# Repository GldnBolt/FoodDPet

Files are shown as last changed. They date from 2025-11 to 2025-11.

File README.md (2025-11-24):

# FoodDPet - Alimentador Automático para Mascotas
## Proposito del Proyecto
FoodDPet es un sistema automatizado diseñado para facilitar la alimentación de mascotas de manera inteligente y controlada. Este proyecto integra hardware embebido y una aplicación web para proporcionar una solución completa que permite a los dueños de mascotas programar y monitorear la alimentación de sus animales de compañía de forma remota.

### DEPENDENCIAS NECESARIAS

### Aplicación Web
- Node.js con npm
- Angular

Instalar Node.js y ejecutar el siguiente comando para instalar las dependencias

``` bash
 npm install 
 npm install -g @angular/cli
```
### Software del microcontrolador

Instalar el IDE de Arduino, e instalar la siguiente librerias: 
- Adafruit VL53L1X por Adafruit

Además de añadir el soporte para tarjetas:
- esp32 por Espressif Systems

### PASOS DE EJECUCIÓN

### Aplicación Web

Dentro de la carpeta WebApp, ejecutar el siguiente comando para abrir la aplicación en modo desarrollo

```bash 
ng serve -o
```

### Software del microcontrolador

Seleccionar desde las tarjetas disponibles en el IDE de Arduino: ESP32S3 Dev Module.

Reemplazar las variables ssid y password por las credenciales de la red a la que se va a conectar el alimentador.

Compilar y subir el código desde el IDE.

Introducir en la aplicación la IP que se imprime después de iniciar el sistema.

### LISTA DE MATERIALES CON COSTOS 
- ESP32: $15,95
- Sensor ultrasónico HC-SR05: $4.49 
- Sensor laser Tof400c: $9.95 
- Stepper Driver A4988: $5.99
- Motor Stepper: $8.30
- Placa Perforada: $3.75
- Cautín y estaño: $24.95
- Transistor NMOS: $0.25
- Pulsador de 4 pines: $0.20
- 2 Resistencias de 220 ohmios: $0.10
- Jumpers: $2.20
- Modelo 3d(Cascasa exterior): $20.00

### DIAGRAMAS DEL CIRCUITO

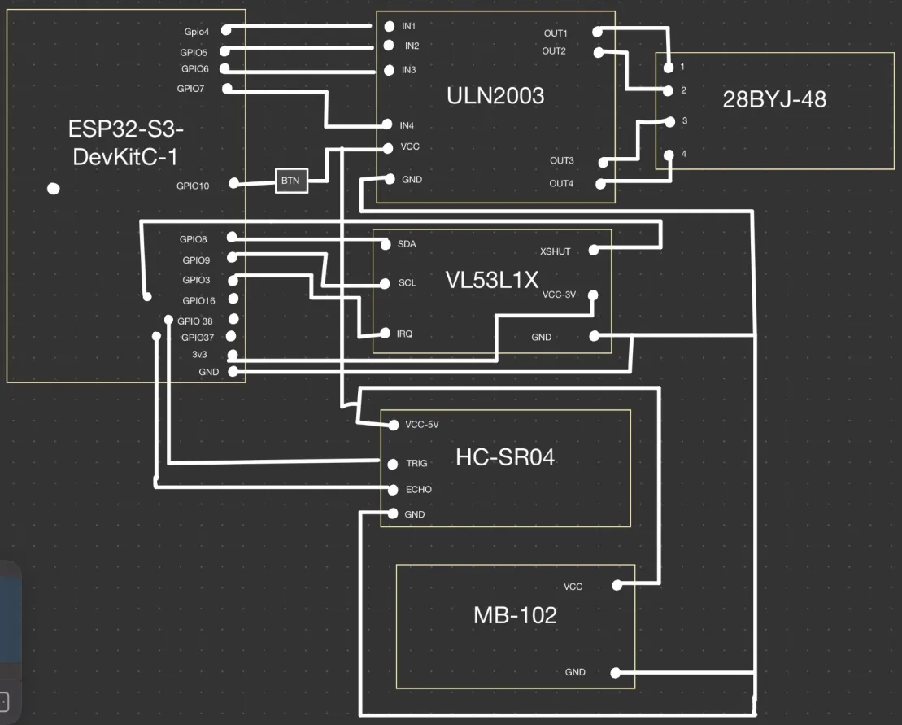
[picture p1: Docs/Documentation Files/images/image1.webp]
Diagrama del circuito


### DEMOSTRACIONES DE USO
En el siguiente enlace se puede observar una demostración del funcionamiento del alimentador automático FoodDPet:
[Demostración FoodDPet](https://www.youtube.com/@fabiola8169)

### Información Adicional
Para más detalle sobre el diseño del proyecto, incluyendo el diseño de hardware, arquitectura de software, aplicación de usuario y comunicación, por favor consulte la documentación completa en el archivo Documentacion.md. Esta documentación incluye descripciones detalladas de los componentes utilizados y demás explicaciones técnicas, así como los diagramas de flujo del software y conexiones de hardware.

Se recomienda además utilizar herramientas de simulación y diseño como Tinkercad para validar los diagramas y conexiones antes de la implementación física del proyecto. Para este proyecto, puede encontrar los mismos en la documentación adjunta. 

Para los diseños 3d de la carcasa se sugiere el uso del software de fusion360 o cualquier otro software de modelado 3d de su preferencia. En la documentación se incluyen los archivos necesarios para la impresión 3d de la carcasa del robot. Se recomienda ajustar las dimensiones según las necesidades específicas del usuario.

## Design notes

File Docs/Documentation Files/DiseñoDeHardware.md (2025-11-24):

# Diseño de Hardware
FoodDPet está construido alrededor de un microcontrolador ESP32, elegido por su capacidad de procesamiento, conectividad Wi-Fi integrada y bajo consumo energético. El ESP32 permite una comunicación eficiente con la aplicación web y maneja múltiples sensores y actuadores necesarios para el funcionamiento del robot. Su elegibilidad se basa en su capacidad de soporte de programas complejos, versatilidad y soporte para diversas interfaces de comunicación.

## Sensores y Actuadores

El robot utiliza una variedad de sensores para monitorear su entorno y asegurar un funcionamiento óptimo. Entre ellos se incluyen:

- Sensor ultrasónico HC-SR05: Utilizado para medir la cercanía del alimento a la tapa del robot para monitorear el nivel de comida.

- Sensor Tof400c : Empleado para la detección precisa de presencia del animal cerca del dispensador para activar el pedido de alimento.

- Motor Stepper: Utilizado para mover el tornillo de dispensado de alimento.

## Analisis de Consumo Energético

El consumo energético del robot ha sido cuidadosamente analizado para garantizar una operación eficiente y prolongada. El ESP32 tiene un consumo promedio de 80 mA en modo activo, mientras que los sensores ultrasónicos y el servomotor tienen consumos adicionales que varían según su uso. Se ha implementado un sistema de gestión de energía por medio de reguladores de voltaje y jacks de alimentacion para tener un consumo optimizado y velar por la duración de los componentes.

## Diagramas de Conexión
A continuación se presentan los diagramas de conexión que ilustran cómo se interconectan los diferentes componentes del robot, se utiliza la herramienta de Tinkercad para el diseño de circuitos y simulaciones. Cabe destacar que el diseño final del hardware no es complemente reflejado en Tinkercad, por temas de limitaciones de la herramienta no todos los componentes están disponibles,
pero se utilizó para validar las conexiones y el funcionamiento básico de los componentes:

Diagrama de conexiones basico

## Consideraciones de Diseño Mecánico

El mecanismo principal del robot consiste en un tornillo infinito, este es el mecanismo principal que permite el movimiento del dispensador de comida. El tornillo infinito es accionado por un motor paso a paso, que proporciona la precisión necesaria para dispensar cantidades exactas de alimento. Este tornillo está hecho de un material resistente y duradero para soportar el uso continuo y las condiciones ambientales a las que estará expuesto el robot. Se opto por este mecanismo debido a su capacidad para proporcionar un movimiento suave y controlado, lo que es esencial para el correcto funcionamiento del dispensador de comida. Por otro lado, el diseño mecánico también incluye un sistema de montaje para los sensores y actuadores, asegurando que estén posicionados de manera óptima para su funcionamiento. Este sistema de montaje es ajustable, permitiendo adaptarse a diferentes tamaños y tipos de alimentos. Se utilizaron materiales ligeros mediante impresion 3d lo que permite crear estructuras sólidas, resistentes, ligeras economicas y modulares lo que permite realizar ajustes y modificaciones de manera sencilla.

## Diseño de Tarjeta Perforada

El diseño de la tarjeta perforada se ha realizado teniendo en cuenta la disposición óptima de los componentes para minimizar interferencias y facilitar el ensamblaje. Se han utilizado software de diseño de PCB para crear un diseño compacto y eficiente, asegurando que todas las conexiones sean robustas y confiables. Este diseño representa la versión final del hardware del robot FoodDPet, optimizado para su funcionalidad y durabilidad:

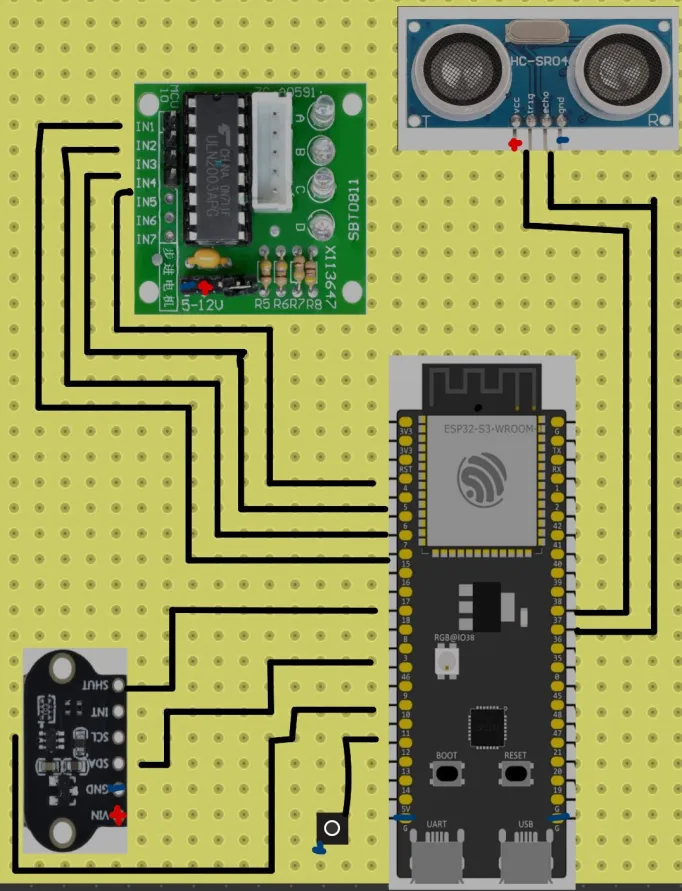
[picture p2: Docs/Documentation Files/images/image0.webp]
Diagrama de la tarjeta perforada
.

## Diseño de la Carcasa

La carcasa del robot ha sido diseñada para proteger los componentes internos y proporcionar una apariencia atractiva y funcional. Se ha utilizado software de modelado 3D para crear un diseño que sea fácil de ensamblar y mantener. La carcasa está hecha de materiales resistentes y ligeros como lo es el PLA. El diseño de la carcasa también incluye aberturas estratégicas para la ventilación y el acceso a los componentes internos, facilitando el mantenimiento y las actualizaciones futuras.

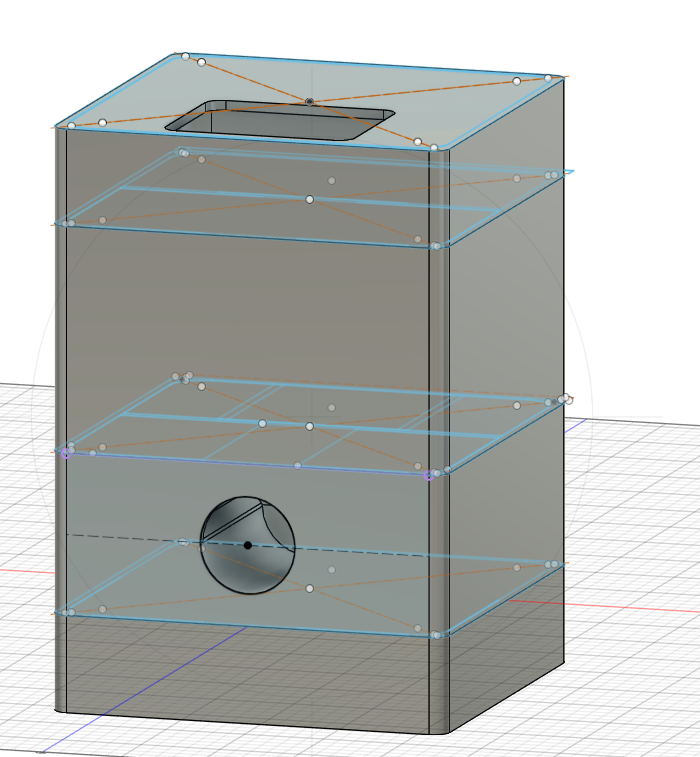
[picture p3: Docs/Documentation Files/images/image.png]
Modelo3D


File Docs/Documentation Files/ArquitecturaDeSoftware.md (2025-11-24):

## Arquitectura de Software

El programa principal que es el que controla el microcontrolador está escrito en Arduino/C++. El programa se conecta a la red WiFi para comunicarse con la aplicación web, mide constantemente los sensores para monitorear el nivel de comida y la presencia de la mascota, ejecuta los horarios programados para dispensar comida automáticamente, y guarda todos los datos importantes en memoria permanente para asegurar que no se pierdan.
El mismo está organizado para ser eficiente y responsivo, al cargar el programa este establece la conexion con los sensores, se conecta a la red WiFi, sincroniza la hora con internet, carga los datos almacenados, y luego entra en un bucle infinito donde atiende las solicitudes de la aplicación web. Este flujo se puede observar mejor de la siguiente manera:

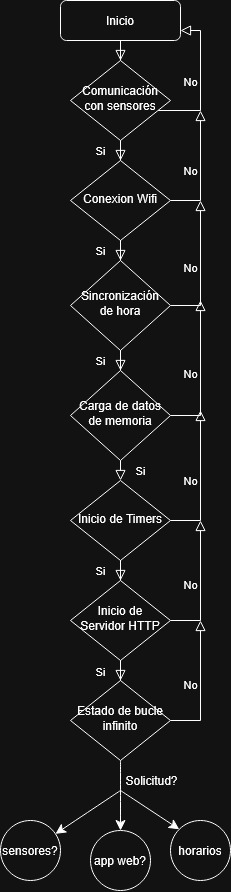
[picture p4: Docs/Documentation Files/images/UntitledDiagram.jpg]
Diagrama de conexiones basico


## Estrategias de Comunicación y Gestión de E/S 

Para los dispositivos de entrada y salida del esp 32 se han implementado diversas estrategias para asegurar una comunicación eficiente y confiable con los sensores y actuadores conectados. La decision fundamental fue combinar la comunicación tanto por interrupciones como por sondeo dependiendo del caso de uso. Lo anterior ya que no era factible ya que si se realizara solamente por sondeo el sistema no sabria exactamente cuando realizar la interrupcion sino que verificaria constantemente el estado de los sensores si hay proximidad lo que generaria un consumo innecesario de recursos y energia. Por otro lado, si se utilizara solamente por interrupciones, los sensor generarían una interrupción cada vez que detecte proximidad, interrumpiendo inmediatamente todo lo que el microcontrolador está haciendo. Por lo que se opto por una solución híbrida que combina ambos métodos para aprovechar las ventajas de cada uno. Más adelante se detallan cada una de las estrategias implementadas.

La primera es la utilizacion de contadores de tiempo que permiten ejecutar tareas periódicas sin bloquear el flujo principal del programa.  
Estos timers funcionan en paralelo con el resto del código, lo que significa que el microcontrolador pueda estar respondiendo a la aplicación web mientras simultáneamente está verificando horarios y escaneando sensores lo anterior permite que el sistema sea responsivo y esté sinconizado. 
Para los timers se definen dos, el timer de cada segundo y el del minuto, el inicial es para verificar en tiempo real los horarios programados y el segundo timer es para escanear el sensor ultrasónico cada minuto y detectar si la mascota está pidiendo comida.

Por otro lado, cada dispositivo tiene su propio protocolo de comunicación específico:

1. Sensor Ultrasonico: Este sensor utiliza un protocolo basado en pulsos. El microcontrolador envía un pulso de activación al sensor, que luego emite un pulso ultrasónico para por realizar las medias.

2. Sensor Láser: Este sensor utiliza el protocolo I2C para comunicarse con el microcontrolador por medio de dos cables SDA y SCL que permiten enviar y recibir datos de manera eficiente.

3. Motor: el microcontrolador activa una salida digital que enciende el motor durante el tiempo necesario.

4. Red WiFi: La comunicación con la aplicación web ocurre constantemente. El ESP32 actúa como un servidor HTTP pequeño que recibe solicitudes GET, POST, PUT y DELETE desde la aplicación, las procesa, y responde con datos en formato JSON.

## Organización de Memoria
Para el almacenamiento de datos se utiliza la memoria EEPROM del microcontrolador. Donde se guardan los horarios de alimentación programados por  medio de un json y las peticiones de alimentacion realizadas por medio de archivo de texto log. Para el manejo de estos archivos se utiliza la libreria de littlefs que permite crear un sistema de archivos en la memoria flash del microcontrolador. Se eligió esta manera de almacenamiento debido a su capacidad para manejar múltiples archivos y su facilidad de uso con el microcontrolador. 

La organización de la memoria se realiza de la siguiente manera:      
- Los primeros bytes de la memoria EEPROM se reservan para almacenar la cantidad de horarios programados. Esto permite al sistema saber cuántos horarios debe cargar al iniciar.

- A continuación, se asigna un bloque de memoria para cada horario programado. Cada bloque contiene la hora y minuto lo que facilita la lectura y escritura de horarios específicos sin afectar otros datos.

- Finalmente, se reserva un espacio adicional para almacenar el historial de alimentaciones realizadas. Cada entrada en el historial incluye la fecha y hora de la alimentación, así como el estado de la operación. Esto permite al usuario revisar el historial completo desde la aplicación web.

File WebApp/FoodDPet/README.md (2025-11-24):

# FoodDPet

This project was generated using [Angular CLI](https://github.com/angular/angular-cli) version 20.3.7.

## Development server

To start a local development server, run:

```bash
ng serve
```

Once the server is running, open your browser and navigate to `http://localhost:4200/`. The application will automatically reload whenever you modify any of the source files.

## Code scaffolding

Angular CLI includes powerful code scaffolding tools. To generate a new component, run:

```bash
ng generate component component-name
```

For a complete list of available schematics (such as `components`, `directives`, or `pipes`), run:

```bash
ng generate --help
```

## Building

To build the project run:

```bash
ng build
```

This will compile your project and store the build artifacts in the `dist/` directory. By default, the production build optimizes your application for performance and speed.

## Running unit tests

To execute unit tests with the [Karma](https://karma-runner.github.io) test runner, use the following command:

```bash
ng test
```

## Running end-to-end tests

For end-to-end (e2e) testing, run:

```bash
ng e2e
```

Angular CLI does not come with an end-to-end testing framework by default. You can choose one that suits your needs.

## Additional Resources

For more information on using the Angular CLI, including detailed command references, visit the [Angular CLI Overview and Command Reference](https://angular.dev/tools/cli) page.

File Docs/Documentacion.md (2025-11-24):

# Documentación de Diseño del Proyecto
---

## **Información del Proyecto**

- **Nombre del Proyecto**: FoodDPet - Alimentador Automatico para Mascotas

- **Equipo**: Equipo FoodDPet

- **Integrantes**:
  - Integrante 1: Andres Blanco Coto
  - Integrante 2: Karina Martínez Guerrero 
  - Integrante 3: Fabiola Meléndez Sequeira
  - Integrante 4: Jeremy Noryan Serracin Oporta
- **Profesor**: Jeferson Gonzalez Gomez
- **Materia**: Arquitectura de Computadores

# Índice

1. [Diseño de Hardware](./Documentation%20files/DiseñoDeHardware.md)
2. [Arquitectura de software](./Documentation%20files/ArquitecturaDeSoftware.md)
3. [Aplicación de usuario y comunicación](./Documentation%20files/AplicacionYComunicacion.md)

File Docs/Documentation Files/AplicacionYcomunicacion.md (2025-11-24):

# Aplicación web desarrollada

La aplicación web de FoodDPet está diseñada para gestionar el sistema automático de alimentación de mascotas. Permite a los dueños de mascotas programar horarios de comida, monitorear el estado del comedero y mantener un registro histórico de las alimentaciones. La aplicación ha sido construida con tecnologías web modernas y responsivas, pensando en una experiencia de usuario intuitiva que cualquiera pueda usar sin necesidad de conocimientos técnicos.

## Arquitectura de la Aplicación

La aplicación está construida con Angular, un framework moderno y robusto para crear aplicaciones web interactivas. Se complementa con PrimeNG, una librería de componentes visuales profesionales y listos para usar, lo que facilita la creación de interfaces atractivas y funcionales. Para la lógica reactiva y manejo de datos en tiempo real, utiliza RxJS. El código está escrito en TypeScript, un lenguaje que extiende JavaScript con características de programación orientada a objetos, haciendo el código más seguro, mantenible y escalable. Las pruebas se realizan con Jasmine y Karma, herramientas estándar en el ecosistema Angular.

## Interfaces de Usuario

La aplicación presenta dos vistas principales, cada una diseñada para cumplir un propósito específico en la gestión de la alimentación de tu mascota. Además de facilitar el control y monitoreo del comedero por medio de tablas, indicadores e historiales explicados más adelante.

1. **Panel de Control (Dashboard)**

Es la primera vista que ves al abrir la aplicación. Aquí se puede ver el estado actual del comedero automático. Incluye: 
- Indicador visual del nivel de comida representado como un porcentaje de 0 a 100% que tan lleno está el comedero.
- Un estado que clasifica si el comedero está "Bajo", "Medio" o "Alto" de comida.
- Una tabla de solicitudes que muestra un histórico de las últimas veces que se le dio comida a la mascota, incluyendo la hora exacta y si la operación se completó correctamente.

La aplicación permite tambien completar o cancelar manualmente una solicitud de alimentación.

2. **Horario de Alimentación (Food Schedule)**

En esta seccion se define cuándo y cuánta comida quieres que reciba tu mascota. Funciona como un calendario de alimentación. La misma permite:
- Agregar nuevos horarios de alimentación, especificando la hora en la que se desea alimentar a la mascota.
- Ver todos los horarios de alimentación programados.
- Editar horarios de alimentación existentes.
- Activar o desactivar horarios de alimentación.
- Eliminar horarios de alimentación cuando ya no sean necesarios.

---
## Protocolos de Comunicación Robot-Aplicación

La aplicación web se comunica con el dispensador automático a través del microcontrolador que es el que conecta todo del sistema. Este chip está conectado por WiFi y constantemente está pendiente de recibir órdenes desde la aplicación.

Al presionar un boton desde la aplicación web la aplicación recopila la información correspondiente y envia un mensaje al microcontrolador el cual procesa la información y ejecuta la acción solicitada. Este microcontrolador también envía datos de vuelta a la aplicación, como el nivel actual de comida y el estado de las solicitudes comunicandose a su misma vez con cada uno de los sensores. 

El microcontrolador tiene un reloj interno sincronizado con los servidores de hora de internet, así que siempre sabe la hora exacta. El mismo cada segundo verifica si la hora actual coincide con alguno de los horarios programados. Cuando coincide se verifica que el horario esté activo y de ser así le ordena al motor que dispense la comida y registra en el historial de que se realizó la alimentación.

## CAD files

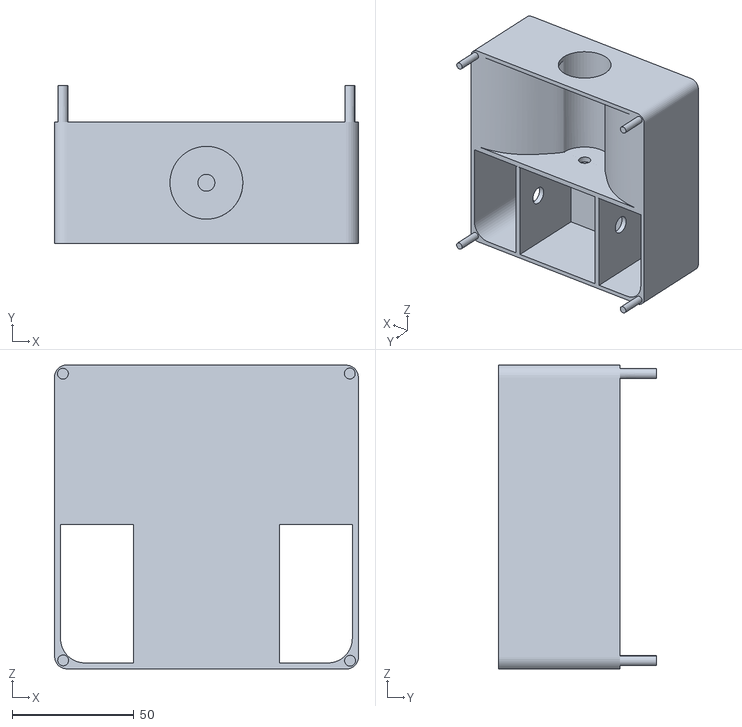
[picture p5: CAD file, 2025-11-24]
Docs/3dDesign/Segundo nivel.stl
125.1 x 65.0 x 125.1

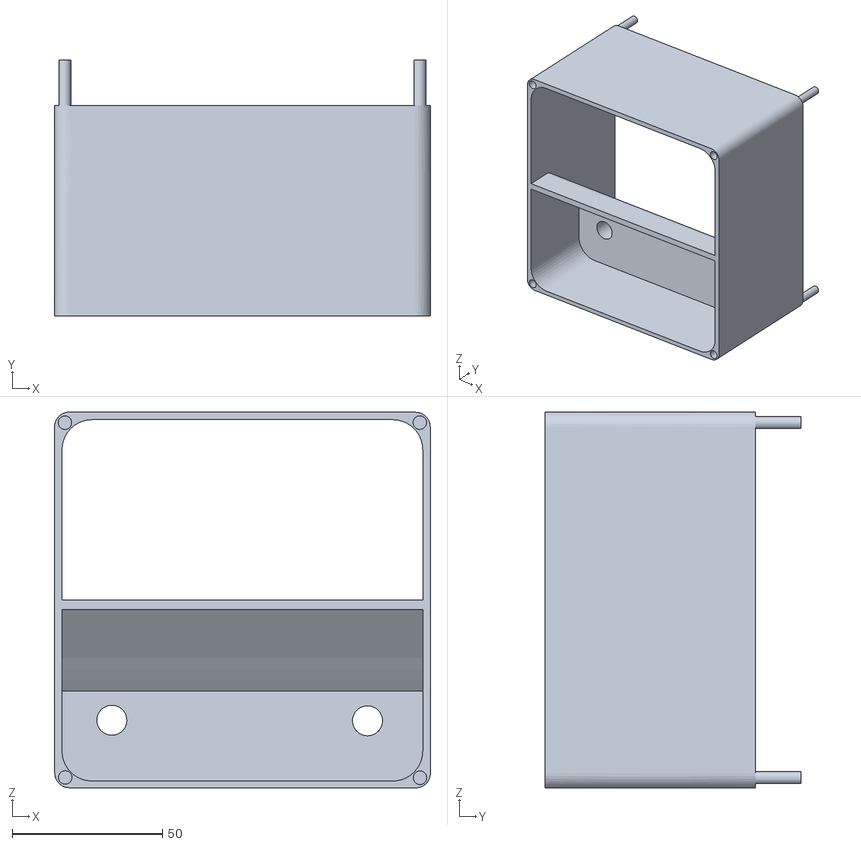
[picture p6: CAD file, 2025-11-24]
Docs/3dDesign/Tercer Nivel.stl
125.1 x 85.0 x 125.1

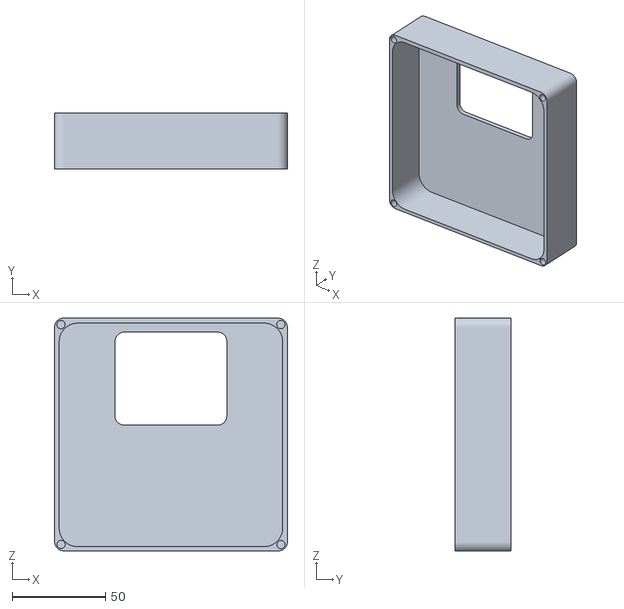
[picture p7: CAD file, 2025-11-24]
Docs/3dDesign/tapa.stl
125.1 x 30.0 x 125.1

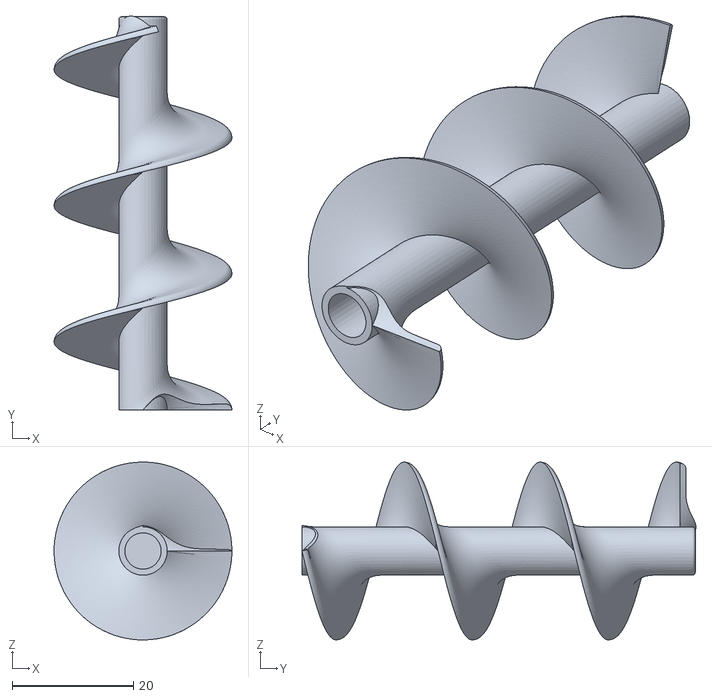
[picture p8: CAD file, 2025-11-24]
Docs/3dDesign/screw.stl
29.4 x 65.1 x 29.4

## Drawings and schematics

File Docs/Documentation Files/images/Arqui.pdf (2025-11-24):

A

1 | 2 | 3 | 4 | 5 | 6

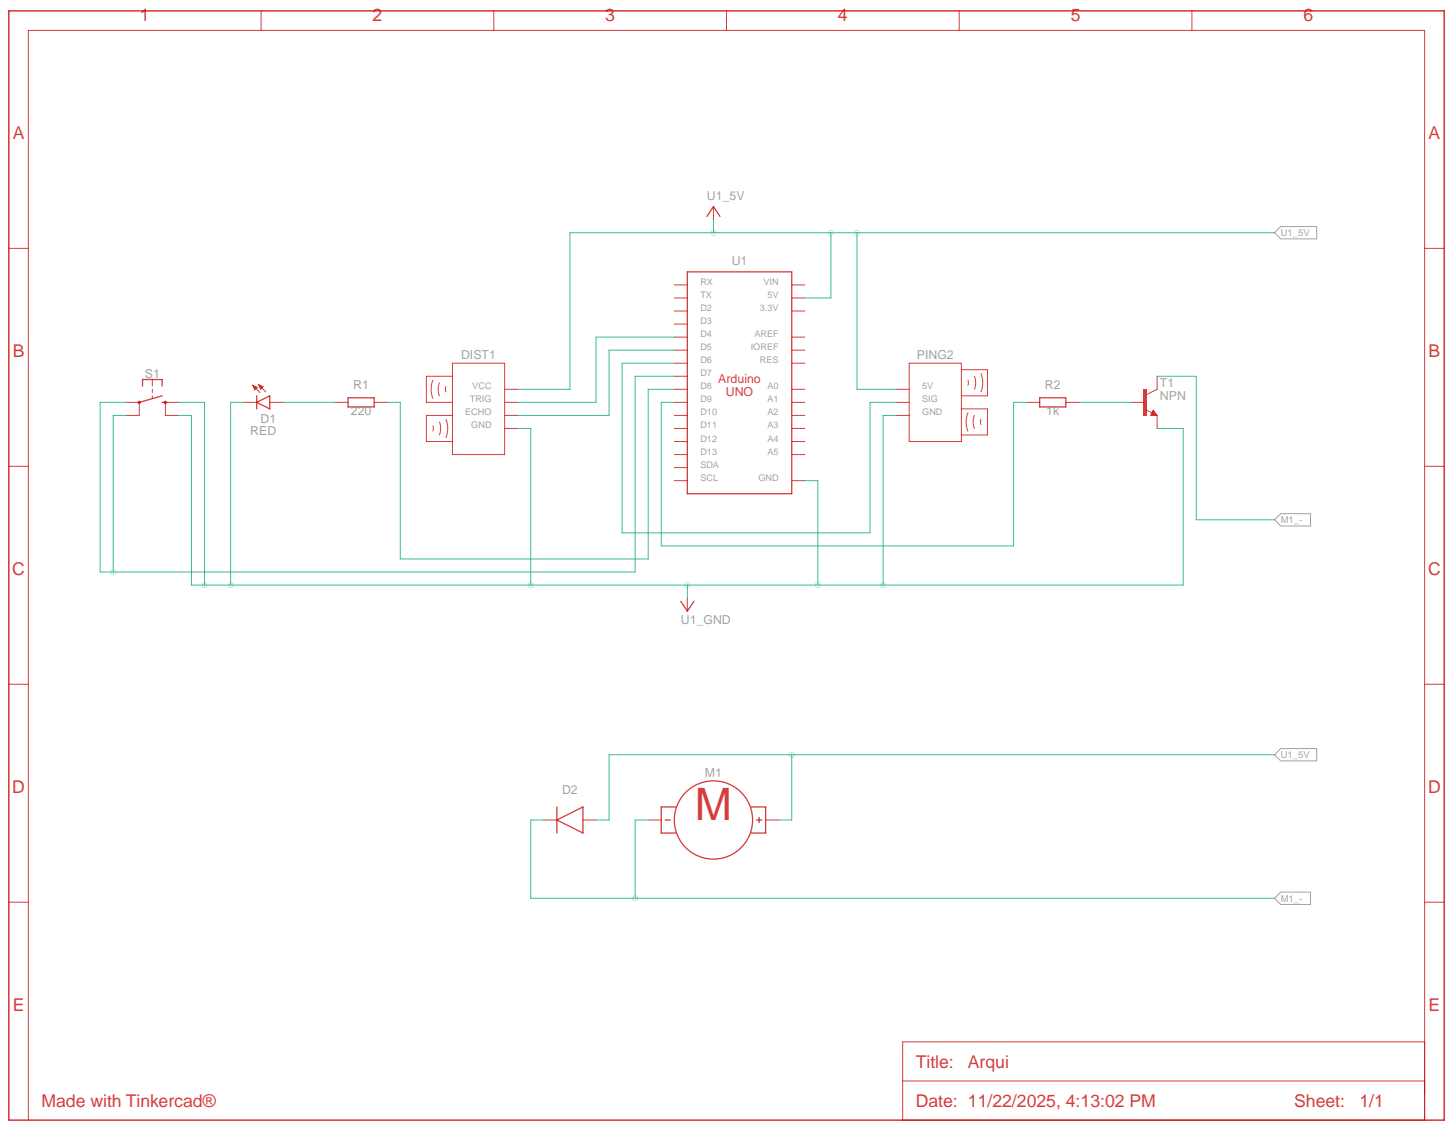
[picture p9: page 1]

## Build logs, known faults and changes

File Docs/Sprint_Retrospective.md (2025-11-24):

# Sprint Retrospective
Este documento detalla las retrospectivas de los sprints realizados durante el desarrollo del proyecto FoodDPet. En cada retrospectiva, se analizan los aspectos positivos, las áreas de mejora y las acciones a tomar para futuros sprints. Lo anterior ayuda a mejorar continuamente el proceso de desarrollo y la calidad del producto final.

### Sprint Retrospective 1
**Fecha:** Noviembre 14, 2025

**Participantes:** 
- Andres Blanco Coto
- Karina Martínez Guerrero
- Fabiola Meléndez Sequeira
- Jeremy Noryan Serracin Oporta

**Lo que salió bien:**
- El equipo cumplió con todos los objetivos del sprint.
- Se mejoró la colaboración entre los miembros del equipo.
- Se recibió retroalimentación positiva de las partes interesadas.
- La comunicación dentro del equipo fue efectiva.

**Lo que podría mejorar:**
- La planificación del sprint podría ser más detallada.
- Algunos miembros del equipo necesitaron más tiempo para completar sus tareas.
- Se debe de mejorar el seguimiento del progreso y actualizacion de tareas en el Jira.

**Acciones a tomar:**
- Recordatorios diarios para actualizar el estado de las tareas en Jira.
- Realizar reuniones de revisión de tareas a mitad del sprint.

### Sprint Retrospective 2
**Fecha:** Noviembre 21, 2025

**Informacion Adicional:**
- Este segundo sprint review se realizó un poco antes de lo planeado debido a la proximidad de las fechas de entrega del proyecto final.
**Participantes:**
- Andres Blanco Coto
- Karina Martínez Guerrero
- Fabiola Meléndez Sequeira
- Jeremy Noryan Serracin Oporta

**Lo que salió bien:**
- Se logró completar la mayoría de las tareas planificadas.
- La comunicación entre los miembros del equipo fue fluida.

**Lo que podría mejorar:**
- La planificación del sprint fue un poco apresurada.
- Algunos miembros del equipo se sintieron abrumados por la carga de trabajo.
- Se debe mejorar una mejor distribución del tiempo de trabajo entre los miembros del equipo.

**Acciones a tomar:**
- Mejorar la planificación del sprint con más tiempo de anticipación.
- Realizar reuniones de seguimiento más frecuentes para asegurar que todos los miembros del equipo estén al día
- Fomentar una mejor distribución del trabajo entre los miembros del equipo para evitar la sobrecarga.

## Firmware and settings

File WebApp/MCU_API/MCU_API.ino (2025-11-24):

/*
 * FoodDPet API REST para ESP32
 * API para gestionar horarios de alimentación y solicitudes
 */

#include "Adafruit_VL53L1X.h"
#include <Wire.h>
#include "time.h"
#include "esp_timer.h"
#include <LittleFS.h>

#include <WiFi.h>
#include <WebServer.h>
WebServer server(80);

#include <ArduinoJson.h>
#include <Stepper.h>

// Pins for distance sensors
#define SDA_PIN 8
#define SCL_PIN 9
#define IRQ_PIN 3
#define XSHUT_PIN 16

#define TRIGGER_PIN 38
#define ECHO_PIN 37

// ---------- Configuración del motor paso a paso (28BYJ-48 + ULN2003) ----------
const int stepsPerRevolution = 2048;  // pasos por vuelta del 28BYJ-48

// Pines del ULN2003 conectados a la ESP32-S3
const int IN1_PIN = 4;   // GPIO4
const int IN2_PIN = 5;   // GPIO5
const int IN3_PIN = 6;   // GPIO6
const int IN4_PIN = 7;   // GPIO7  (OJO: XSHUT_PIN se movió al GPIO16)

// Botón local para pruebas del dispensador
const int BUTTON_PIN = 10;   // GPIO10, botón entre GPIO10 y GND

// Objeto Stepper
// Si el motor vibra y no gira, probar el otro orden de pines comentado abajo.
Stepper myStepper(stepsPerRevolution, IN1_PIN, IN3_PIN, IN2_PIN, IN4_PIN);
// Alternativa:
// Stepper myStepper(stepsPerRevolution, IN1_PIN, IN2_PIN, IN3_PIN, IN4_PIN);

bool motorOcupado     = false;
int  ultimoEstadoBoton = HIGH;  // con INPUT_PULLUP: HIGH = no presionado


Adafruit_VL53L1X vl53 = Adafruit_VL53L1X(XSHUT_PIN, IRQ_PIN);

// Configuración para el timer
const char* ntpServer = "pool.ntp.org";
const long gmtOffset_sec = -6 * 3600;  // Ajusta según tu país
const int daylightOffset_sec = 0;

volatile bool second_tick = false;
volatile bool minute_tick = false;

void IRAM_ATTR secondCallback(void* arg) {
  second_tick = true;
}

void IRAM_ATTR minuteCallback(void* arg) {
  minute_tick = true;
}

esp_timer_handle_t second_timer;
esp_timer_handle_t minute_timer;


// Configuración WiFi
const char* ssid = "Los Pardos";
const char* password = "Bienvenido";

// Estructura para Solicitudes
struct FoodRequest {
  String hora;
  String estado;  // "Completed", "Pending", "Cancelled"
};

// Estructura para Horarios
struct Schedule {
  int id;
  String time;
  bool active;
  // Added variables for interrupt
  int hour;
  int minute;
  void (*func)();
  bool triggered;
};

// Datos de prueba - Solicitudes
FoodRequest requests[10];
int requestCount = 0;

// Datos de prueba - Horarios
Schedule schedules[10];
int scheduleCount = 0;

// Estado del dispensador
int fullnessPercentage = 100;

void setup_sensors() {
  pinMode(TRIGGER_PIN, OUTPUT);
  pinMode(ECHO_PIN, INPUT);

  pinMode(XSHUT_PIN, OUTPUT);
  digitalWrite(XSHUT_PIN, HIGH);
  delay(120);

  Wire.begin(SDA_PIN, SCL_PIN, 100000);  // 100 kHz

  Serial.println("Escaneando I2C...");

  Wire.beginTransmission(0x29);
  byte error = Wire.endTransmission();

  if (error == 0) Serial.println(">>> Sensor detectado en 0x29");
  else Serial.println(">>> NO se detectó sensor I2C en 0x29");

  if (!vl53.begin(0x29, &Wire)) {
    Serial.print(F("Error on init of VL sensor: "));
    Serial.println(vl53.vl_status);
    while (1) delay(10);
  }

  Serial.println(F("VL53L1X sensor OK!"));

  vl53.setTimingBudget(50);
}


void setup_timer() {
  configTime(gmtOffset_sec, daylightOffset_sec, ntpServer);
  Serial.println("Sincronizando hora...");
  delay(2000);

  // Timer 1 second
  const esp_timer_create_args_t second_args = {
    .callback = &secondCallback,
    .arg = NULL,
    .dispatch_method = ESP_TIMER_TASK,
    .name = "timer_1s"
  };

  esp_timer_create(&second_args, &second_timer);
  esp_timer_start_periodic(second_timer, 1'000'000);

  const esp_timer_create_args_t minute_args = {
    .callback = &minuteCallback,
    .arg = NULL,
    .dispatch_method = ESP_TIMER_TASK,
    .name = "timer_1m"
  };

  esp_timer_create(&minute_args, &minute_timer);
  // 60,000,000 µs = 1 minuto
  esp_timer_start_periodic(minute_timer, 60'000'000ULL);
}

void setup() {
  Serial.begin(115200);
  delay(1000);

  // Inicializar control del motor paso a paso y botón local
  pinMode(BUTTON_PIN, INPUT_PULLUP);
  myStepper.setSpeed(20);  // 20 rpm ≈ 1 vuelta en ~3 s

  // Inicializar datos de prueba
  initializeTestData();

  // Conectar a WiFi
  Serial.println("\nConectando a WiFi...");
  WiFi.begin(ssid, password);

  while (WiFi.status() != WL_CONNECTED) {
    delay(500);
    Serial.print(".");
  }

  Serial.println("\n¡WiFi conectado!");
  Serial.print("Dirección IP: ");
  Serial.println(WiFi.localIP());

  // setup both distance sensors
  Serial.println("Configurando sensores");
  pinMode(TRIGGER_PIN, OUTPUT);
  pinMode(ECHO_PIN, INPUT);
  // Comentar setup_Sensors por error del i2c
  setup_sensors();

  if (!LittleFS.begin(true)) {
    Serial.println("Error inicializando sistema de archivos");
  } else {
    Serial.println("Sistema de archivos listo");
    loadSchedulesFromFS();
    loadRequestsFromFS();
  }

  printRequestsLog();
  print_requests();

  // Configurar rutas de la API
  setupRoutes();

  // Iniciar servidor
  server.begin();
  Serial.println("Servidor HTTP iniciado");


  setup_timer();
  Serial.println("Sistema listo.");
}

void loop() {
  // Verificar los flags de los timers
  if (second_tick) {
    second_tick = false;
    check_events();
  }

  if (minute_tick) {
    minute_tick = false;
    //Serial.println(">>> Timer 1 minuto activado");
    check_proximity();
  }

  // Botón local: si se presiona, disparamos un ciclo de dispensado
  int estadoBoton = digitalRead(BUTTON_PIN);
  bool botonRecienPresionado = (ultimoEstadoBoton == HIGH && estadoBoton == LOW);
  if (botonRecienPresionado && !motorOcupado) {
    Serial.println("Boton local presionado -> dispensar comida");
    dispense_food();
  }
  ultimoEstadoBoton = estadoBoton;

  // Atender peticiones HTTP
  server.handleClient();
}

void initializeTestData() {
  // Inicializar solicitudes de prueba
  requests[0] = { "2024-11-15T10:00:00", "Pending" };
  requests[1] = { "2024-11-15T14:30:00", "Cancelled" };
  requests[2] = { "2024-11-15T09:15:00", "Completed" };
  requests[3] = { "2024-11-15T16:45:00", "Pending" };
  requestCount = 4;

  // Inicializar horarios de prueba
  schedules[0] = { 1, "12:55", true, 12, 55, dispense_food, false };
  schedules[1] = { 2, "14:00", true, 14, 0, dispense_food, false };
  schedules[2] = { 3, "20:00", false, 20, 0, dispense_food, false };
  scheduleCount = 3;
}

void setupRoutes() {
  // Handler para todas las solicitudes OPTIONS (CORS preflight)
  server.onNotFound([]() {
    if (server.method() == HTTP_OPTIONS) {
      handleCORS();
    } else {
      handleNotFound();
    }
  });

  // Rutas para el Dashboard
  server.on("/api/fullness", HTTP_GET, handleGetFullness);
  server.on("/api/fullness", HTTP_OPTIONS, handleCORS);

  server.on("/api/requests", HTTP_GET, handleGetRequests);
  server.on("/api/requests", HTTP_OPTIONS, handleCORS);

  server.on("/api/requests/complete", HTTP_POST, handleCompleteRequest);
  server.on("/api/requests/complete", HTTP_OPTIONS, handleCORS);

  server.on("/api/requests/cancel", HTTP_POST, handleCancelRequest);
  server.on("/api/requests/cancel", HTTP_OPTIONS, handleCORS);

  server.on("/api/refill", HTTP_POST, handleRefill);
  server.on("/api/refill", HTTP_OPTIONS, handleCORS);

  // Rutas para Horarios
  server.on("/api/schedules", HTTP_GET, handleGetSchedules);
  server.on("/api/schedules", HTTP_POST, handleCreateSchedule);
  server.on("/api/schedules", HTTP_OPTIONS, handleCORS);

  server.on("/api/schedules/update", HTTP_PUT, handleUpdateSchedule);
  server.on("/api/schedules/update", HTTP_OPTIONS, handleCORS);

  server.on("/api/schedules/delete", HTTP_DELETE, handleDeleteSchedule);
  server.on("/api/schedules/delete", HTTP_OPTIONS, handleCORS);

  // Ruta de prueba
  server.on("/", HTTP_GET, handleRoot);
}

// ========== HANDLERS DE DASHBOARD ==========

void sendCORSHeaders() {
  server.sendHeader("Access-Control-Allow-Origin", "*");
  server.sendHeader("Access-Control-Allow-Methods", "GET, POST, PUT, DELETE, OPTIONS");
  server.sendHeader("Access-Control-Allow-Headers", "Content-Type, Authorization");
  server.sendHeader("Access-Control-Max-Age", "86400");
}

void handleCORS() {
  sendCORSHeaders();
  server.send(204);
}

void handleGetFullness() {
  sendCORSHeaders();
  StaticJsonDocument<200> doc;

  fullnessPercentage = get_tank_level();

  doc["percentage"] = fullnessPercentage;

  if (fullnessPercentage >= 75) {
    doc["status"] = "Alto";
  } else if (fullnessPercentage >= 50) {
    doc["status"] = "Medio";
  } else {
    doc["status"] = "Bajo";
  }

  String response;
  serializeJson(doc, response);

  server.send(200, "application/json", response);
}

void handleGetRequests() {
  sendCORSHeaders();
  DynamicJsonDocument doc(2048);
  JsonArray array = doc.to<JsonArray>();
  loadRequestsFromFS();

  for (int i = 0; i < requestCount; i++) {
    JsonObject obj = array.createNestedObject();
    obj["hora"] = requests[i].hora;
    obj["estado"] = requests[i].estado;
  }

  String response;
  serializeJson(doc, response);

  server.send(200, "application/json", response);
}

void handleCompleteRequest() {
  sendCORSHeaders();
  if (server.hasArg("plain")) {
    String body = server.arg("plain");

    StaticJsonDocument<200> doc;
    DeserializationError error = deserializeJson(doc, body);

    if (error) {
      server.send(400, "application/json", "{\"error\":\"Invalid JSON\"}");
      return;
    }

    String hora = doc["hora"];

    // Buscar y actualizar la solicitud
    for (int i = 0; i < requestCount; i++) {
      if (requests[i].hora == hora) {
        requests[i].estado = "Completed";
        dispense_food();
        //print_requests();
        updateRequestsLog();
        server.send(200, "application/json", "{\"message\":\"Request completed\"}");
        return;
      }
    }

    server.send(404, "application/json", "{\"error\":\"Request not found\"}");
  } else {
    server.send(400, "application/json", "{\"error\":\"No data received\"}");
  }
}

void handleCancelRequest() {
  sendCORSHeaders();
  if (server.hasArg("plain")) {
    String body = server.arg("plain");

    StaticJsonDocument<200> doc;
    DeserializationError error = deserializeJson(doc, body);

    if (error) {
      server.send(400, "application/json", "{\"error\":\"Invalid JSON\"}");
      return;
    }

    String hora = doc["hora"];

    // Buscar y actualizar la solicitud
    for (int i = 0; i < requestCount; i++) {
      if (requests[i].hora == hora) {
        requests[i].estado = "Cancelled";
        //print_requests();
        updateRequestsLog();
        server.send(200, "application/json", "{\"message\":\"Request cancelled\"}");
        return;
      }
    }

    server.send(404, "application/json", "{\"error\":\"Request not found\"}");
  } else {
    server.send(400, "application/json", "{\"error\":\"No data received\"}");
  }
}

void handleRefill() {
  sendCORSHeaders();

  // Primero: dispensar comida (mueve el motor)
  dispense_food();

  // Luego de dispensar, actualizar el nivel del tanque
  fullnessPercentage = get_tank_level();

  StaticJsonDocument<200> doc;
  doc["message"] = "Bowl refilled successfully";
  doc["percentage"] = fullnessPercentage;

  String response;
  serializeJson(doc, response);

  server.send(200, "application/json", response);
}


// ========== HANDLERS DE HORARIOS ==========

void handleGetSchedules() {
  sendCORSHeaders();
  DynamicJsonDocument doc(2048);
  JsonArray array = doc.to<JsonArray>();

  for (int i = 0; i < scheduleCount; i++) {
    JsonObject obj = array.createNestedObject();
    obj["id"] = schedules[i].id;
    obj["time"] = schedules[i].time;
    obj["active"] = schedules[i].active;
  }

  String response;
  serializeJson(doc, response);

  server.send(200, "application/json", response);
  //print_schedules();
  saveSchedulesToFS();
}

void handleCreateSchedule() {
  sendCORSHeaders();
  if (server.hasArg("plain")) {
    String body = server.arg("plain");
    StaticJsonDocument<300> doc;
    DeserializationError error = deserializeJson(doc, body);

    if (error) {
      server.send(400, "application/json", "{\"error\":\"Invalid JSON\"}");
      return;
    }

    if (scheduleCount >= 10) {
      server.send(400, "application/json", "{\"error\":\"Maximum schedules reached\"}");
      return;
    }

    // Crear nuevo horario
    schedules[scheduleCount].id = scheduleCount + 1;
    schedules[scheduleCount].time = doc["time"].as<String>();
    schedules[scheduleCount].active = doc["active"];
    // Added to configure interrupt handler
    schedules[scheduleCount].hour = schedules[scheduleCount].time.substring(0, 2).toInt();
    schedules[scheduleCount].minute = schedules[scheduleCount].time.substring(3, 5).toInt();
    schedules[scheduleCount].func = dispense_food;
    schedules[scheduleCount].triggered = false;

    scheduleCount++;

    StaticJsonDocument<200> response;
    response["message"] = "Schedule created successfully";
    response["id"] = scheduleCount;

    String responseStr;
    serializeJson(response, responseStr);

    server.send(201, "application/json", responseStr);
  } else {
    server.send(400, "application/json", "{\"error\":\"No data received\"}");
  }

  //print_schedules();
  saveSchedulesToFS();
}

void handleUpdateSchedule() {
  sendCORSHeaders();
  if (server.hasArg("plain")) {
    String body = server.arg("plain");
    StaticJsonDocument<300> doc;
    DeserializationError error = deserializeJson(doc, body);

    if (error) {
      server.send(400, "application/json", "{\"error\":\"Invalid JSON\"}");
      return;
    }

    int id = doc["id"];

    // Buscar y actualizar el horario
    for (int i = 0; i < scheduleCount; i++) {
      if (schedules[i].id == id) {
        if (doc.containsKey("time")) {
          schedules[i].time = doc["time"].as<String>();
          // Added to configure interrupt handler
          schedules[i].hour = schedules[i].time.substring(0, 2).toInt();
          schedules[i].minute = schedules[i].time.substring(3, 5).toInt();
        }
        if (doc.containsKey("active")) {
          schedules[i].active = doc["active"];
          schedules[i].triggered = false;
        }
        //print_schedules();
        saveSchedulesToFS();
        server.send(200, "application/json", "{\"message\":\"Schedule updated\"}");
        return;
      }
    }

    server.send(404, "application/json", "{\"error\":\"Schedule not found\"}");
  } else {
    server.send(400, "application/json", "{\"error\":\"No data received\"}");
  }
}

void handleDeleteSchedule() {
  sendCORSHeaders();
  if (server.hasArg("plain")) {
    String body = server.arg("plain");
    StaticJsonDocument<200> doc;
    DeserializationError error = deserializeJson(doc, body);

    if (error) {
      server.send(400, "application/json", "{\"error\":\"Invalid JSON\"}");
      return;
    }

    int id = doc["id"];

    // Buscar y eliminar el horario
    for (int i = 0; i < scheduleCount; i++) {
      if (schedules[i].id == id) {
        // Mover todos los elementos siguientes una posición atrás
        for (int j = i; j < scheduleCount - 1; j++) {
          schedules[j] = schedules[j + 1];
          saveSchedulesToFS();
        }
        scheduleCount--;

        server.send(200, "application/json", "{\"message\":\"Schedule deleted\"}");
        return;
      }
    }

    server.send(404, "application/json", "{\"error\":\"Schedule not found\"}");
  } else {
    server.send(400, "application/json", "{\"error\":\"No data received\"}");
  }
}

// ========== HANDLERS AUXILIARES ==========

void handleRoot() {
  String html = "<html><body>";
  html += "<h1>FoodDPet API</h1>";
  html += "<p>API REST funcionando correctamente</p>";
  html += "<h2>Endpoints disponibles:</h2>";
  html += "<ul>";
  html += "<li>GET /api/fullness - Obtener estado de llenado</li>";
  html += "<li>GET /api/requests - Obtener solicitudes</li>";
  html += "<li>POST /api/requests/complete - Completar solicitud</li>";
  html += "<li>POST /api/requests/cancel - Cancelar solicitud</li>";
  html += "<li>POST /api/refill - Rellenar dispensador</li>";
  html += "<li>GET /api/schedules - Obtener horarios</li>";
  html += "<li>POST /api/schedules - Crear horario</li>";
  html += "<li>PUT /api/schedules/update - Actualizar horario</li>";
  html += "<li>DELETE /api/schedules/delete - Eliminar horario</li>";
  html += "</ul>";
  html += "<p>IP: " + WiFi.localIP().toString() + "</p>";
  html += "</body></html>";

  server.send(200, "text/html", html);
}

void handleNotFound() {
  sendCORSHeaders();
  server.send(404, "application/json", "{\"error\":\"Endpoint not found\"}");
}

int measure_distance(int sensor) {
  int distance;
  // Laser sensor
  if (sensor == 1) {
    bool start = vl53.startRanging();
    if (start) {
      if (vl53.dataReady()) {
        // new measurement for the taking!
        distance = vl53.distance();
        if (distance == -1) {
          // something went wrong!
          Serial.print(F("No se pudo obtener distancia: "));
          Serial.println(vl53.vl_status);
          return -1;
        } else {
          // data is read out, time for another reading!
          vl53.clearInterrupt();
          vl53.stopRanging();
          return distance;
        }
      }
    } else {
      return -1;
    }
  } else {
    // Ultrasonic sensor
    // Clears the trigPin
    digitalWrite(TRIGGER_PIN, LOW);
    delayMicroseconds(2);

    // Sets the trigPin on HIGH state for 10 micro seconds
    digitalWrite(TRIGGER_PIN, HIGH);
    delayMicroseconds(10);
    digitalWrite(TRIGGER_PIN, LOW);

    // Reads the echoPin, returns the sound wave travel time in microseconds
    long duration;
    duration = pulseIn(ECHO_PIN, HIGH);

    // Calculating the distance
    distance = duration * 0.034 / 2;

    // Prints the distance on the Serial Monitor
    Serial.print(String(distance));
    Serial.println(" cm");
    return distance;
  }
}


int get_tank_level() {
  int distance = measure_distance(1);
  Serial.println(distance);
  if (distance < 0) {
    Serial.println("No se pudo tomar medida");
    return -1;
  } else if (distance >= 0 && distance < 50) {
    Serial.println("Full tank");
    return 100;
  } else if (distance >= 50 && distance < 100) {
    Serial.println("Almost full tank");
    return 75;
  } else if (distance >= 100 && distance < 120) {
    Serial.println("Half full tank");
    return 50;
  } else if (distance >= 120 && distance < 140) {
    Serial.println("Almost empty tank");
    return 25;
  } else {
    Serial.println("Empty tank");
    return 0;
  }
}


// ------------------- Interrupciones -----------------------------

void check_events() {
  struct tm timeinfo;
  if (!getLocalTime(&timeinfo)) {
    Serial.println("No se pudo obtener la hora...");
    return;
  }

  for (int i = 0; i < scheduleCount; i++) {

    // comparar hora actual y hora del evento
    if (timeinfo.tm_hour == schedules[i].hour && timeinfo.tm_min == schedules[i].minute) {

      if (!schedules[i].triggered && schedules[i].active) {
        Serial.println("Ejecutando evento ...");
        schedules[i].func();
        schedules[i].triggered = true;
      }
    } else {
      schedules[i].triggered = false;
    }
  }
}

void print_schedules() {
  Serial.println("------ Eventos --------");
  for (int i = 0; i < scheduleCount; i++) {
    Serial.print("ID: ");
    Serial.println(schedules[i].id);
    Serial.print("Time: ");
    Serial.println(schedules[i].time);
    Serial.print("Hour: ");
    Serial.println(schedules[i].hour);
    Serial.print("Minute: ");
    Serial.println(schedules[i].minute);
    Serial.print("Active: ");
    Serial.println(schedules[i].active);
    Serial.print("Triggered: ");
    Serial.println(schedules[i].triggered);
    Serial.println("---------------------");
  }
}

void print_requests() {
  Serial.println("------ Solicitudes --------");
  for (int i = 0; i < requestCount; i++) {
    Serial.print("Estado: ");
    Serial.println(requests[i].estado);
    Serial.print("Hora: ");
    Serial.println(requests[i].hora);
    Serial.println("-----------------------");
  }
}

void saveSchedulesToFS() {
  File file = LittleFS.open("/schedules.json", "w");
  if (!file) {
    Serial.println("No se pudo abrir schedules.json para escribir");
    return;
  }

  DynamicJsonDocument doc(2048);
  JsonArray arr = doc.to<JsonArray>();

  for (int i = 0; i < scheduleCount; i++) {
    JsonObject o = arr.createNestedObject();
    o["id"] = schedules[i].id;
    o["time"] = schedules[i].time;
    o["active"] = schedules[i].active;
  }

  serializeJson(doc, file);
  file.close();
  Serial.println("Horarios guardados en memoria interna");
}


void loadSchedulesFromFS() {
  if (!LittleFS.exists("/schedules.json")) {
    Serial.println("No hay schedules.json, usando valores por defecto");
    return;
  }

  File file = LittleFS.open("/schedules.json", "r");
  if (!file) {
    Serial.println("Error leyendo schedules.json");
    return;
  }

  DynamicJsonDocument doc(2048);
  DeserializationError err = deserializeJson(doc, file);
  file.close();

  if (err) {
    Serial.println("JSON inválido en schedules.json");
    return;
  }

  JsonArray arr = doc.as<JsonArray>();
  scheduleCount = 0;

  for (JsonObject o : arr) {
    schedules[scheduleCount].id = o["id"];
    schedules[scheduleCount].time = o["time"].as<String>();
    schedules[scheduleCount].active = o["active"];
    schedules[scheduleCount].hour = schedules[scheduleCount].time.substring(0, 2).toInt();
    schedules[scheduleCount].minute = schedules[scheduleCount].time.substring(3, 5).toInt();
    schedules[scheduleCount].func = dispense_food;
    scheduleCount++;
  }

  Serial.println("Horarios cargados desde memoria interna");
}
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

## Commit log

2025-11-15 [Update] Adding refill button
2025-11-17 Backend connection addition
    Implemented on a ESP32, has to change ip address manually, still working on that
2025-11-21 [feature] working timer and interrupts for schedules
2025-11-22 [feature] timer to handle proximity measurement for food requests
2025-11-22 [fix] correct date format and update requests
    [MCU_API.ino]
2025-11-23 Modificaciones para el funcionamiento del motor
2025-11-24 documentation important updates
    [Segundo nivel.stl, Tercer Nivel.stl, screw.stl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]
